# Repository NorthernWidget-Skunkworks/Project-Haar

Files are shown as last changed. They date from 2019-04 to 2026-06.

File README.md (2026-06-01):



# Project-Haar

***Mechanical, electrical, and firmware files for a rugged and submersible temperature, pressure, and relative-humidity sensor***

## Namesake and history

Haar in Ben Bhraggie Woods, Sutherland
***Haar in Ben Bhraggie Woods, Sutherland, Scotland.*** *Photo by Andrew Tryon.*

Project Haar takes its codename from the [North Sea fogs that roll across Britain](https://en.wikipedia.org/wiki/Haar_(fog)).
[Bobby Schulz](https://github.com/bschulz1701) designed it after the consistently-near-0C temperatures and 100% relative humidity of [Chimborazo Volcano](https://en.wikipedia.org/wiki/Chimborazo), Ecuador, claimed the lives of many brave but misguided [BME-280](https://www.adafruit.com/product/2652) units, who then catastrophically bricked their I2C buses and those of their associated data loggers, thus taking down a large fraction of our hydromet network.

Determined to avoid future issues with persistently condensing humidity, we worked to design a unit that would survive in this environment, and indeed, withstand full submersion.

## Technical specifications
<picture>
  <source media="(prefers-color-scheme: dark)" srcset="Documentation/images/Haar_v010_top_annotated_20200427_LIGHT.png">
  <!-- <source media="(prefers-color-scheme: light)" srcset="Documentation/images/Haar_v010_top_annotated_20200427.png"> -->
  Haar bare board
</picture>
<!-- ![Haar bare board](Documentation/images/Haar_v010_top_annotated_20200427.png) -->

### Electronic Hardware

* Microcontroller (computer) core
  * ATTiny1634
  * [Firmware](Firmware/) written in Arduino-compatible C++
  * Firmware upload via a [0.05" (1.27 mm) pitch 2x3 ICSP header](https://www.digikey.com/product-detail/en/samtec-inc/FTS-103-01-L-D/SAM1156-03-ND/1109979)
* Sensors
  * Relative humidity and temperature sensor: [SHT35-DIS-F2.5KS](https://www.digikey.com/product-detail/en/sensirion-ag/SHT35-DIS-F2.5KS/1649-1067-1-ND/6212138) with [PTFE membrane](https://www.sensirion.com/fileadmin/user_upload/customers/sensirion/Dokumente/2_Humidity_Sensors/Datasheets/Sensirion_Humidity_Sensors_SHT3x_Datasheet_Filter_Membran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) for water and dust protection
    * Humidity
      * Range: 0--100%
      * Accuracy: ±1.5%
      * Resolution: 0.01%
      * Long-term drift: <0.25%/yr
    * Temperature
      * Range: -40--125 °C
      * Accuracy: ±0.2 °C
      * Resolution: 0.01 °C
      * Long-term drift: <0.01 °C/yr
  * Atmospheric pressure and temperature sensor: [LPS35HW](https://www.st.com/en/mems-and-sensors/lps35hw.html)
    * Pressure
      * Range: 260 to 1260 mbar
      * Accuracy, calibrated: ±1 mbar
      * Accuracy, uncalibrated: ±4 mbar
      * Resolution: 1/4096 mbar (approx. 0.00024 mbar)
    * Temperature
      * Range, full accuracy: 0 to 60 °C
      * Accuracy: ±1.5 °C
      * Resolution: 0.01 °C
* Connections and communications protocols
  * [4-pin "HardMount" plug](https://www.digikey.com/product-detail/en/te-connectivity-amp-connectors/1838893-2/A97650-ND/1764165) ([3D drawing](http://www.te.com/commerce/DocumentDelivery/DDEController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))
  * I2C
* Power
  * Voltage limits: 3.3V ~ 5.5V
  * Power consumption: 
    * Peak = 5.21mA @ 3.3V
    * Sleep = 0.524 mA @ 3.3V
    * Mean (5 Hz sample rate) = 0.583 mA @ 3.3V
    * Mean (1 Hz sample rate) = 0.780 mA @ 3.3V
* Submersible with its Gore-Tex sealed housing
* Entirely IP67 or greater rated components
* Response Time
  * Temperature: &tau; = 377s
  * Humidity: &tau; = 505s
  * Pressure: &tau; &lt;1s

### Electronic Software and Firmware

* Programmable using the Arduino IDE https://www.arduino.cc/en/main/software
* [Firmware](Firmware/) available in this repository. [`Haar_Firmware.ino`](Firmware/Haar_Firmware/Haar_Firmware.ino) is the standard firmware to be used. 
* [Software](https://github.com/NorthernWidget-Skunkworks/Haar_Library) to use this sensor with Arduino-compatible devices
* Open-source licensing via GNU GPL 3.0

### Weatherproofing and enclosure
* Low-VOC conformal coating as recommended on Page 3 of the [humidity and temperature sensor data sheet](https://www.sensirion.com/fileadmin/user_upload/customers/sensirion/Dokumente/2_Humidity_Sensors/Application_Note/Sensirion_Humidity_Sensors_Handling_Instructions.pd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). We used [Dow Corning 1-2577 Low VOC Conformal Coating](https://www.digikey.com/product-detail/en/1-2577+CONFORMAL+CTG+453G/2275-1-2577CONFORMALCTG453G-ND/11494980/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).
* Fully sealed housing with removable [breathable-membrane (IP68) vent](https://www.digikey.com/product-detail/en/amphenol-ltw/VENT-PS1NGY-O8002/1754-1221-ND/7898276)

> [!WARNING]
> If applying conformal coating, ensure none comes in contact with the sensor orifices themselves, see Senserion Handling Instructions [example](Documentation/images/ConformalApplication.png)

Haar: in housing

## Assembly

### Sensor circuit board

[Bill of Materials](Production/Haar_HardMount_BoM_0v1.csv)

[PCB Gerber Files](Production/Gerbers_2020-02-20.zip)

Assembling this sensor is possible by hand with sufficient skill and the following tools:
* Temperature-controlled soldering iron
* Hot-air rework station
* Equipment for stenciling with solder paste
* ESD-safe tweezers and workstation
* Solder wick

Many components on this board are fine pitch and/or have difficult to access pads. However, there are not very many components. We would suggest hand assembly using tweezers, stenciled solder paste, and a hot-air rework station. A soldering iron will be helpful -- if not outright essential -- for attaching the "Hard Mount" plug and (if desired) the 2x3 pin ICSP header to upload the firmware.
<!-- >> THOUGHT: I have basic instructions for assembly on the [Project Walrus](https://github.com/NorthernWidget-Skunkworks/Project-TPDH-Walrus) README; I will not reproduce these here just yet, as we might want to set up a separate assembly guide, mostly with good links to existing resources, since our writing something of this nature would be to reinvent the wheel. -->

After finishing the main board assembly, solder the HardMount plug onto the four SMD pads with the notch (for plug orientation) at the bottom side of the board.

### Housing and cabling

Haar: exploded view

Two different housings have been designed to be used in different situations depending on how much robustness is required by the sensor. 
**Closed:**
For maximal robustness a [sealed IP67 rated housing](Mechanical/ClosedBody/ClosedBody.stl) was designed. This housing can be constructed using FDM printing with ABS plastic and acetone smoothing - an [FDM optimized version](Mechanical/ClosedBody_FDM/ClosedBody_FDM.stl) of the design was made featuring an eyelet to hang the enclosure from during the smoothing process. However, results will be significantly better with PA12 SLS nylon - readily available from many print houses.

Render of Closed Enclosure

**Open:**
For maximal responsiveness an [open structure enclosure](Mechanical/OpenBody/OpenBody.stl) was designed to allow airflow while still protecting the sensor from mechanical damage. This enclosure has been tested with FDM and SLA printing, methods will depend on your desired material properties.

Render of Closed Enclosure

#### Parts required

* Sealing plug with cable such as this [-40 degree PVC-jacketed one](https://www.digikey.com/product-detail/en/alpha-wire/AR0400105-SL357/AR0400105SL357-ND/6555497) or [this set of Digi-Key search results for all those that are 3 meters or less in both -40 degree rated PVC and in ](https://www.digikey.com/products/en/cable-assemblies/circular-cable-assemblies/448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); these come in [a variety of lengths from 0.6 to 20 meters](http://www.alphawire.com/en/Products/Connectivity/AlphaConnect/Cordsets/AR0400105) ([Digi-Key search results](https://www.digikey.com/products/en/cable-assemblies/circular-cable-assemblies/448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)). You may also [attach a plug to your own cable](http://www.alphawire.com/en/Products/Connectivity/AlphaConnect/FieldAttachable/200ARS7). Note that I2C communications become iffy for any cable longer than 3 meters.
* [3D-printed housing barrel](Mechanical/ClosedBody_FDM), tapped (see below). We recommend light-colored plastic to reduce radiative heating.
* [4-pin HardMount plug](https://www.digikey.com/product-detail/en/te-connectivity-amp-connectors/1838893-2/A97650-ND/1764165)
* [Amphenol breathable vent](https://www.digikey.com/product-detail/en/amphenol-ltw/VENT-PS1NGY-O8002/1754-1221-ND/7898276)

#### Soldering the HardMount attachment to your board

If it is not already attached, you will need to solder the [4-pin HardMount plug](https://www.digikey.com/product-detail/en/te-connectivity-amp-connectors/1838893-2/A97650-ND/1764165) onto the four SMD pads at the end of the board far from the isolated humidity sensor. You should do so with the notch (for plug orientation) at the bottom side of the board.

Our recommendation for by-hand assembly:
* Add small pillows of solder to each of the four pads, enough to create contact with the HardMount solder cups but not so much that it is not possible to slide the HardMount plug over them.
* Slide the HardMount plug on; it will take a bit of finesse to keep it from being pushed off of the solder pillows.
* Using some Blu Tack (or equivalent), fix the board and HardMount plug in place
* Double-check that the notch in the HardMount plug is on the back side of the board
* Solder on the first connection
* Check whether the board is straight; reflow the solder as needed until the connection is secure
* Solder the second connection
* Flip the board, ensuring that it is straight (if not, make changes)
* Solder the other two solder-cup connections

> [!TIP]
> Sometimes the 3D printed threads are not sufficiently fine to work smoothly. In this case, you can 'repair' the threads using a metal tap. 
>
> The cable side thread is an [M16 x 1.5](https://www.mcmaster.com/26015A263/), and the vent side is a [M12 x 1.5](https://www.mcmaster.com/26015A613/) - More economical taps can be found, these placed here for referance.

#### Cable

Here we assume that you are using [standard Alpha Wire cables with waterproof attachments]([Alpha Wire 5004C](https://www.digikey.com/product-detail/en/alpha-wire/5004C-SL001/5004CSL001-ND/484976). Because of the wire insulation colors available for these cables and the locations of their attachment points to the [4-pin "HardMount" plug](https://www.digikey.com/product-detail/en/te-connectivity-amp-connectors/1838893-2/A97650-ND/1764165) ([3D drawing](http://www.te.com/commerce/DocumentDelivery/DDEController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)), **our HardMount devices do NOT match standard wire-color definitions (or any kind of standard)**. Wire-color definitions are:

<picture>
  <source media="(prefers-color-scheme: dark)" srcset="Documentation/images/Pinout_LIGHT.png">
  Haar Connector Pinout
</picture>

| **Color** | **Connection** |
|---|---|
| Brown | V+ (3.3-5.5 V) |
| White | GND |
| Black | SDA |
| Blue | SCL |

For reference, these are the definitions of the four pads to which the [HardMount connector](https://www.digikey.com/product-detail/en/te-connectivity-amp-connectors/1838893-2/A97650-ND/1764165) attaches:
* Top left: SDA
* Top right: SCL
* Bottom left: VCC (3.3V to 5.5V)
* Bottom right: GND

## Firmware

### Downloading and installing the Arduino IDE

Go to https://www.arduino.cc/en/main/software. Choose the proper IDE version for your computer. For Windows, we suggest the non-app version to have more control over Arduino; this might change in the future. You will have to add custom libraries, so the web version will not work (at least, as of the time of writing). Download and install the Arduino IDE. Open it to begin the next steps.

### AVR ISP

To install firmware on the Haar board, you use the [2x3-pin 6-pin ICSP (also called ISP) header](https://www.digikey.com/product-detail/en/samtec-inc/FTS-103-01-L-D/SAM1156-03-ND/1109979) with a special device called an "in-circuit system programmer" (or just "in-system programmer; yup, that's what the acronym stands for).

Many devices exist to upload firmware, including:
* The official [AVR ISP mkII](http://ww1.microchip.com/downloads/en/DeviceDoc/Atmel-42093-AVR-ISP-mkII_UserGuide.pdf) (no longer produced but available used)
* Using an [Arduino as an ISP](https://www.arduino.cc/en/tutorial/arduinoISP)
* The versatile [Olimex AVR-ISP-MK2](https://www.olimex.com/Products/AVR/Programmers/AVR-ISP-MK2/open-source-hardware) (recommended)
* The [Adafruit USBtinyISP](https://www.adafruit.com/product/46)

> [!IMPORTANT] 
> The Haar has a [half-sized (0.05" pitch) ICSP header](https://www.digikey.com/product-detail/en/samtec-inc/FTS-103-01-L-D/SAM1156-03-ND/1109979). Therefore, you will need to have the appropriate 2x3-pin header to form a connection - see detailed [assmbly instructions](Hardware/ISP_Cable_Assembly.md).

<!-- ***Note: Be sure to download and/or update drivers for your ISP.*** -->

> [!NOTE]
> Frequently on Windows machines the driver configuration of the ISP programmer can become problematic. See discussion of how to get drivers and the use of Zadig to configure them in this [Sparkfun Guide](https://learn.sparkfun.com/tutorials/pocket-avr-programmer-hookup-guide/installing-drivers)

### Uploading the firmware

Using this ISP, upload (as of the time of writing): [the Arduino sketch in this folder](Firmware/Haar_Firmware/). To do so, follow these steps:

1. Open the Arduino IDE.
2. Follow [these instructions](https://github.com/SpenceKonde/ATTinyCore/blob/master/Installation.md) to install the [ATTinyCore board definitions](https://github.com/SpenceKonde/ATTinyCore)
3. Select [ATTiny1634](https://github.com/SpenceKonde/ATTinyCore/blob/master/avr/extras/ATtiny_1634.md) **(No bootloader)**

> [!CAUTION]
> Check your ISP target voltage before you connect! Make sure the target voltage is set to 3.3v, 5v can damage the sensor irreparably 

4. Plug your ISP of choice into your computer (via a USB cable) and onto the 6-pin header. There are two ways to place it on; the header is aligned such that the ribbon cable should be facing away from the board while programming. If this fails without being able to upload, try flipping the header around. This should both power the board and provide communications.
5. Go to Tools --> Programmer and select the appropriate programmer based on what you are using.
6. Go to Tools --> Burn Bootloader. Yes, we know that you just selected "ATTiny1634 (No bootloader)", but this step sets the fuses, which configure their internal oscillator and brown-out detection.
7. Go to Sketch --> Upload Using Programmer. After several seconds, you learn whether you succeeded or failed. Hopefully it worked!

Upload using programmer

***Uploading using the in-system programmer.***

> [!NOTE] 
> **Linux Users:** You must supply permissions to the Arduino IDE for it to be able to use the ICSP, or you will have to run it using `sudo`. The former option is better; the latter is easier in the moment.

## Register map and firmware internals

The Haar firmware runs on an ATTiny1634 and exposes an I2C register map to the host logger. The default I2C address is `0x42`.

The device exposes a flat, byte-addressable virtual address space. The master writes a 1-byte starting address, then reads up to 32 bytes in one transaction. Pages are 32-byte aligned.

Two layouts exist: the **current firmware** (deployed) and the **proposed** layout under [NW-Device-Specification](https://github.com/NorthernWidget/NW-Device-Specification) Schema 1, which the firmware will be updated to implement.

### Current register map (deployed firmware)

10-byte array, no schema byte, no device name. The library reads one register at a time (no bulk page read). The master triggers a conversion by writing `0x01` to address `0x00`; the firmware clears bit 0 when the measurement is complete.

```
0x00        Config       bit 0 = sample trigger (master writes 1; cleared when done)
0x01        —            unused
0x02–0x03   Temp LPS35HW int16, raw (library: val/100.0 → °C)
0x04–0x05   Temp SHT31   uint16, raw SHT31 counts (library: -45 + 175×val/65535 → °C)
0x06–0x08   Pressure     24-bit, raw LPS35HW counts (library: val/4096.0 → hPa)
0x09–0x0A   Humidity     uint16, raw SHT31 counts (library: 100×val/65535 → % RH)
             ⚠ 0x0A is out of bounds — Reg[10] ends at 0x09
```

### Proposed register map (NW-Device-Specification Schema 1)

Two 32-byte pages. Identity is EEPROM-backed; sensor data is SRAM-backed. No calibration page (both sensors are factory-calibrated with no user calibration step).

**Page 0 (0x00–0x1F) — Identity (EEPROM)**

```
Block 0 (0x00–0x07)   Core identity
  0x00        0x01              Schema (NW-Device-Specification v1)
  0x01–0x04   'H','a','a','r'   Device name (ASCII)
  0x05–0x07   0x00,0x00,0x00    Null padding

Block 1 (0x08–0x0F)   Version
  0x08        HW major
  0x09        HW minor
  0x0A        FW patch          (NW combined-repo convention)
  0x0B–0x0D   0x00,0x00,0x00    Unused (combined repo)
  0x0E–0x0F   0x00,0x00         Reserved

Block 2 (0x10–0x17)   Serial number
  0x10–0x11   0x48,0x01         Board type ('H' = 0x48, revision index 1)
  0x12–0x13   [manufacture]     Group ID
  0x14–0x15   [manufacture]     Unique ID
  0x16–0x17   0x00,0x00         FirmwareID (legacy, reserved)

Block 3 (0x18–0x1F)   Integrity + administration
  0x18–0x1C   0x00 ×5           Reserved
  0x1D        0x00              Magic byte (reserved; purpose TBD)
  0x1E        [computed]        CRC-8 of bytes 0x00–0x1D
  0x1F        0x42              I2C address (writable; 0xFF = use default)
```

**Page 1 (0x20–0x3F) — Sensor data (SRAM)**

```
Block 0 (0x20–0x27)   SHT31 — temperature + humidity
  0x20        Status       bit 0=ready, bit 1=SHT31 fault, bit 2=LPS35HW fault,
                           bit 7=pan-fault
  0x21        Extended faults (reserved, 0x00)
  0x22–0x23   Temp SHT31   int16, 0.01 °C, little-endian
  0x24–0x25   Humidity     uint16, 0.01 % RH, little-endian
  0x26–0x27   Reserved

Block 1 (0x28–0x2F)   LPS35HW — pressure + temperature
  0x28–0x2B   Pressure     uint32, 0.01 hPa, little-endian
  0x2C–0x2D   Temp LPS35HW int16, 0.01 °C, little-endian
  0x2E–0x2F   Reserved

Block 2–3 (0x30–0x3F)   Reserved
```

Check bit 0 of 0x20 before using any measurement. If clear, all other Page 1 bytes are stale.

---

## Writing a program to connect to the Haar sensor

Once the  is bootloaded and connected with a LiDAR Lite sensor, you should be able to use any standard Arduino device to connect to it and read its data.

### Very simple Arduino code

This code is intended for any generic Arduino system.

```c++
// Include the Haar library
#include "Haar.h"

// Declare variables -- just as strings
String header;
String data;

// Instantiate class
Haar myTPRH;

void setup(){
    // Begin Serial connection to computer at 38400 baud
    Serial.begin(38400);
    // Obtain the header just once
    header = myTPRH.getHeader();
    // Print the header to the serial monitor
    Serial.println(header);
}

void loop(){
    // Take one reading every (10 + time to take reading) seconds
    // and print it to the screen
    myTPRH.updateMeasurements();
    data = myTPRH.getString();
    Serial.println(data);
    delay(10000); // Wait 10 seconds before the next reading, inefficiently
}
```

### Northern Widget Margay code

The [Margay data logger](github.com/NorthernWidget-Skunkworks/Project-Margay) is the lightweight and low-power open-source data-logging option from Northern Widget. It saves data to a local SD card and includes on-board status measurements and a low-drift real-time clock. We have written [a library to interface with the Margay](github.com/NorthernWidget-Skunkworks/Margay_Library), which can in turn be used to link the Margay with sensors.

```c++
// Include the libraries
#include "Margay.h"
#include "Haar.h"

// Declare variables -- just as strings
String header;
String data;

// Instantiate classes
Haar myTPRH;
Margay Logger; // Margay v2.2; UPDATE CODE TO INDICATE THIS

// Empty header to start; will include sensor labels and information
String Header = "";

// I2CVals for Haar
uint8_t I2CVals[] = {0x42}; // DEFAULT

//Number of seconds between readings
uint32_t updateRate = 60;

void setup(){
    Header = Header + myTPRH.getHeader();
    Logger.begin(I2CVals, sizeof(I2CVals), Header);
    initialize();
}

void loop(){
    initialize();
    Logger.run(update, updateRate);
}

String update() {
    initialize();
    return myTPRH.getString();
}

void initialize(){
    myTPRH.begin();
}
```

### Northern Widget Okapi code

>> Currently nearly identical to Margay code, by design. Add telemetry with Particle Boron.

```c++
// Include the libraries
#include "Okapi.h"
#include "Haar.h"

// Declare variables -- just as strings
String header;
String data;

// Instantiate classes
Haar myTPRH;
Okapi Logger;

// Empty header to start; will include sensor labels and information
String Header = "";

// I2CVals for Haar
uint8_t I2CVals[] = {0x42}; // DEFAULT

//Number of seconds between readings
uint32_t updateRate = 60;

void setup(){
    Header = Header + myTPRH.getHeader();
    Logger.begin(I2CVals, sizeof(I2CVals), Header);
    initialize();
}

void loop(){
    initialize();
    Logger.run(update, updateRate);
}

String update() {
    initialize();
    return myTPRH.getString();
}

void initialize(){
    myTPRH.begin();
}
```

## Characterization

### Response time

<!-- ![Lab fridge test](Documentation/images/Haar_T9602_vent_test_lab_fridge.png)

***Response-time testing.*** *Our initial tests demonstrate that, with the vent detached, the Haar exhibits sensitivity and response time similar to the [T9602 temperature and relative humidity sensor](https://www.amphenol-sensors.com/images/stories/moisture-humidity/main-T9602-Mod-4.png). With the vent cap on, this response is dampened significantly.* -->
This sensor was tested for using an impulse for each variable (temperature, pressure, humidity) and for each housing type (closed, open). The details of each of these evaluations can be found in the testing documentation: [Temperature](Testing/Temperature/README.md), [Pressure](Testing/Pressure/README.md), [Humidity](Testing/Humidity/README.md). A summary of these results, along with visuals of the step response, is presented here.

Approximate time to equilibrium for each variable and sensor type
| **Sensor** | Temperature | Pressure | Humidity | 
|---:|:---:|:---:|:---:|
| Control | 105s | &lt;1s | 18 min |
| Haar, Closed | 75s | &lt;1s | 31.75 min |
| Haar, Open | 12.5 min | &lt;1s | 10.25 min |

Temperature Step Response Graph

Humidity Step Response Graph

This response time information should serve as a guide to the choice of housing. In situations where very fast response time is required *and* the sensor will not be subjected to environmental extremes (e.g. in a radiation shield on a meteorological station) an open housing can be used. However, in cases where the hazards of the environment are a priority (e.g. a sensor in the flood plane of a river to calibrate a depth sensor) a closed housing should be used.

<!-- >> @bschulz1701: Application note about when to use the cap? Notes about the IP ratings of the devices and practical ratings as well? And I've been looking for a M12 vent without any membrane so it can still physically protect the sensor (or act as a roof for rain) but have not yet found one. Thoughts on this?
>> @awickert: The cap would desire to be used when there is the potential for the device to become fully submerged and slow response time is not a problem (for getting system averages instead of response time or quick variance). All elements of the device (uncapped) are rated to >IP67, however, the conformal coating of the board is not specifically rated for any pressure. It would likely survive breif immersion but not for extended periods of time. As for the a cap with no membrane: since be 3D print the body, we would just design a body with a "roof" instead of a thread at the top, and holes or slots in the side, whichever we desire. Then instead of replacing the end cap, you just replace the entire body (which just screws on to the bottom). This would actually make it a bit easier to make, since it would be one less thread that would need to be made by hand. -->

## NW-Device-Specification — Schema 1, Page 0

Implements [NW-Device-Specification](https://github.com/NorthernWidget/NW-Device-Specification) Schema 1. The 32-byte identity block (Page 0) is stored at the top of EEPROM:

```
Block 0:  Schema=0x01, Name='H','a','a','r',0x00,0x00,0x00
Block 1:  HW major=[mfr], HW minor=[mfr], FW patch=[mfr], 0x00,0x00,0x00, Reserved
Block 2:  Board type=0x4801 ('H'=0x48, rev 1), Group ID=[mfr], Unique ID=[mfr], FirmwareID=0x0000
Block 3:  Reserved, Magic=0x00, CRC=[computed], I2C address=0x48
```

Legacy deployed units use I²C address `0x42` (pre-Schema-1).

## Acknowledgments

Support for this project provided by:

UMN ESCI
<br/>
<br/>
NSF

WMO

<br/>
<br/>
<br />This work is licensed under a <a rel="license" href="http://creativecommons.org/licenses/by-sa/4.0/">Creative Commons Attribution-ShareAlike 4.0 International License</a>.

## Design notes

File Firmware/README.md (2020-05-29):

`"Haar_Firmware.ino`: current most final firmware: still needs a bit of cleanup, but has full functionality.

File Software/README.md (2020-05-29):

`Haar_InterfaceDev.ino` is a development script used for testing the functionality of the Haar firmware be reading from the device (this code is meant to be run on the logger side for testing and development only)

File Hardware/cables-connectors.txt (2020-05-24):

"HardMount" plug: TE Connectivity 1838893-2: https://www.digikey.com/product-detail/en/te-connectivity-amp-connectors/1838893-2/A97650-ND/1764165
"HardMount cable: Alpha Wire AR0400105 SL357: https://www.digikey.com/product-detail/en/alpha-wire/AR0400105-SL357/AR0400105SL357-ND/6555497
Cable for non-HardMount version: Alpha Wire 5004C: https://www.digikey.com/product-detail/en/alpha-wire/5004C-SL001/5004CSL001-ND/484976
0.05" pitch 2x3 ICSP header (optional; can hold in place as well): Samtec FTS-103-01-L-D: https://www.digikey.com/product-detail/en/samtec-inc/FTS-103-01-L-D/SAM1156-03-ND/1109979

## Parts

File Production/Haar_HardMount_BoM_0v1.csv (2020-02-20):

Qty | Value | Device | Package | Parts | Description | DIGIKEY | DISP | MF | MPN | PROD_ID | VALUE | VALUE_PART
1 |  | ATTINY1634QFN | QFN20 | U3 | ATtiny1634 8 bit AVR Microcontroller | ATTINY1634-MURCT-ND |  | Atmel | ATTINY1634-MUR
3 | 0.1uF | C-EU0.1UFC0402 | C0402 | C3, C4, C5 | CAPACITOR, European symbol | 490-4759-1-ND |  | Murata | GCM155R71C104KA55D
3 | 10k | R-EU_10KR0402 | R0402 | R1, R2, R3 | RESISTOR, European symbol | 311-10.0KHRCT-ND |  | Yageo | RC0603FR-0710KL |  |  | 10k
1 | 2.2uH | INDUCTOR0805 | 0805 | L1 | Genaric inductor | 732-2953-1-ND |  | Wurth | 74479775222
1 | 2N7002 | MOSFET-NCH-2N7002PW | SOT323 | Q1 | N-channel MOSFETs | 2N7002W-FDICT-ND |  | Diodes Incorporated | 2N7002W-7-F | TRANS-11151 | 2N7002
2 | 4.7uF | C-EUC0402 | C0402 | C1, C2 | CAPACITOR, European symbol | 490-14306-1-ND |  | Murata | GRM155R61A475MEAAD
1 | AVRISP1.27MM | AVRISP1.27MM | 2X3_1.27 | ISP1 | AVR ISP HEADER
1 | LPS35HW | LPS35HW | CCLGA10L | U2 | LPS3xHW - Digital Water Resistant Pressure Sensor | 497-16706-1-ND | LPS35HW | ST | LPS35HWTR
1 | SHT35DFN | SHT35DFN | DFN_8_2.5X2.5 | U1 | SHT3x - Digital Humidity and Temperature Sensor | 1649-1067-1-ND | SHT35 | Sensirion | SHT35-DIS-F2.5KS
1 | SOLDERCUP_CONN_QUAD | SOLDERCUP_CONN_QUAD | SOLDERCUP_CONN_QUAD | J1
1 | TPS62237DRY | TPS62237DRY | DRY0006A | U4 | TPS6223xx - Ultra Small Step Down Converter (Buck) | 296-39454-1-ND | TPS62237 | TI | TPS62237DRYR
1 | TXS0102DQM | TXS0102DQM | DQM_R-PX2SON-N8 | U5 | TXS0102 - 2 Channel Bidirectional Voltage Level Translator | 296-28435-1-ND |  | TI | TXS0102DQMR

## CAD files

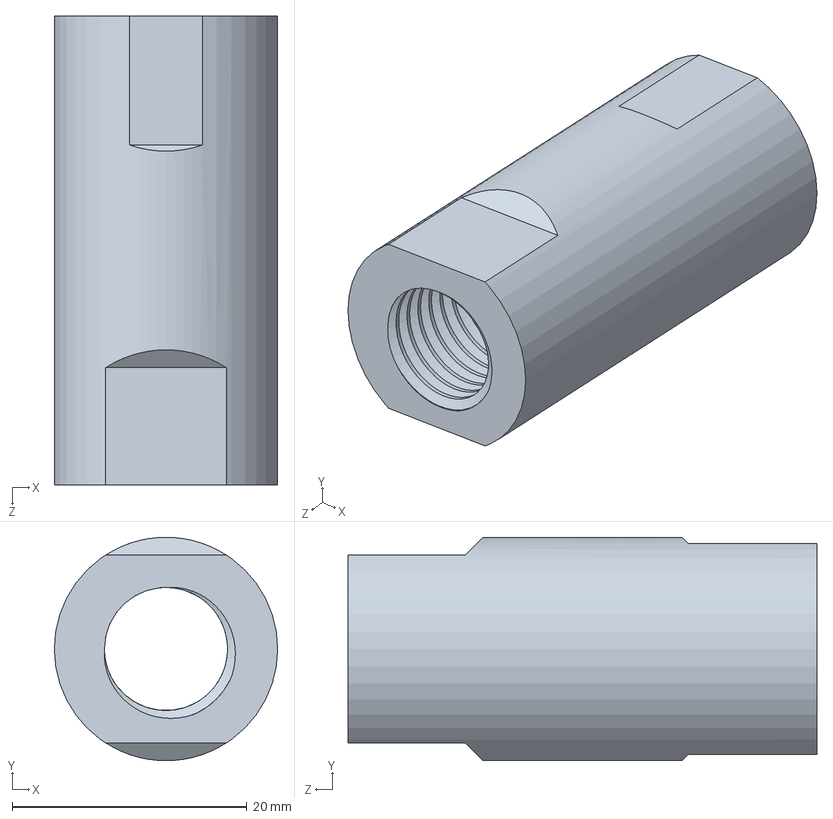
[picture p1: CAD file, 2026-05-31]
Mechanical/ClosedBody/ClosedBody.SLDPRT
19.1 x 19.1 x 40.0 mm

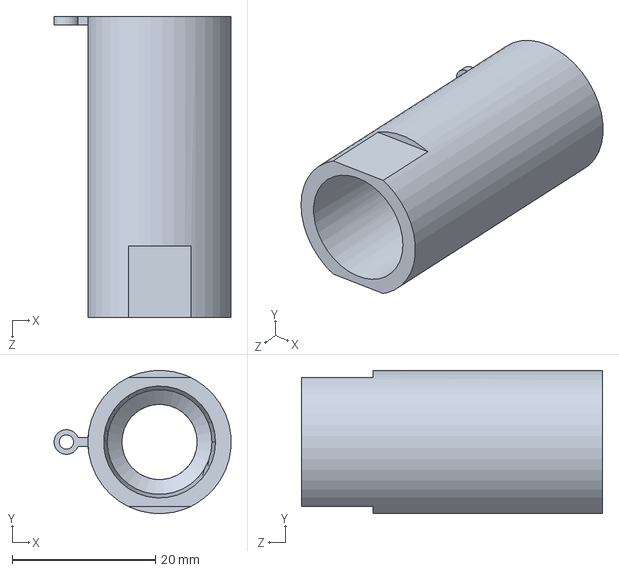
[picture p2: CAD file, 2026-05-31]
Mechanical/ClosedBody_FDM/ClosedBody_FDM.SLDPRT
24.7 x 20.0 x 42.0 mm

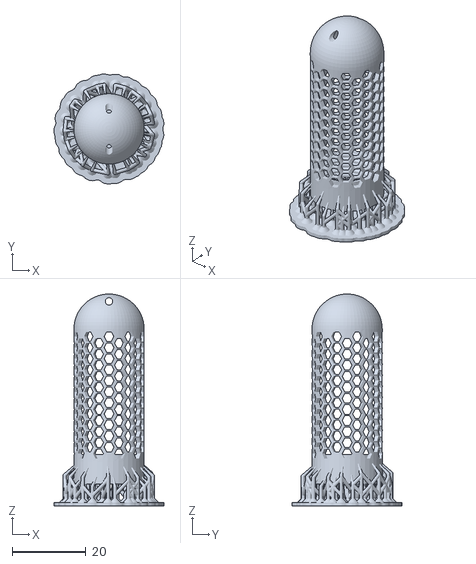
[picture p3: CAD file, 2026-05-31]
Mechanical/OpenBody/HAAR_001_-_OpenBody-v001_SUPPORTED.stl
29.8 x 29.9 x 57.5

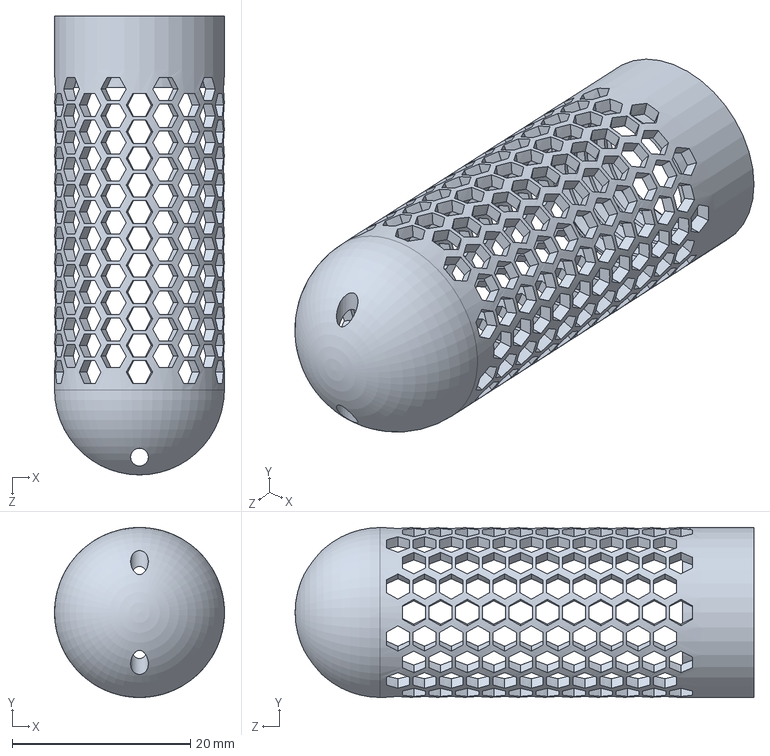
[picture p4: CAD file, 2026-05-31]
Mechanical/OpenBody/OpenBody.SLDPRT
19.1 x 19.1 x 51.5 mm

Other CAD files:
Mechanical/ClosedBody/ClosedBody.STL
Mechanical/ClosedBody_FDM/ClosedBody_FDM.STL
Mechanical/OpenBody/OpenBody.STL

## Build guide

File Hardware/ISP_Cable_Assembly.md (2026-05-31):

# ISP Cable Assembly Documentation 

### Components
* [10 Pos 0.1" Pitch Connector - 3M 89110-0101HA](https://www.digikey.com/en/products/detail/3m/89110-0101HA/1239030)
* [6 Pos 0.05" Pitch Connector - 3M 45106-000030](https://www.digikey.com/en/products/detail/3m/45106-000030/4475133)
* [Ribbon Cable, 30 AWG - Molex 1000570267](https://www.digikey.com/en/products/detail/molex/1000570267/6025715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)

### Assembly
* Install cable in 6 position connector using standard method
* Separate each wire in ribbon cable using x-acto knife and separate out several inches (about 2in/5cm)
* Insert each wire into the corresponding slot in the 10 position connector 
* Carefully clamp down the 10 position connector, being careful not to cross any of the wires

ICSP Pinout

#### Reference Material
[Olimex AVR ISP Mk2 Programming Interfaces](https://www.olimex.com/Products/AVR/Programmers/AVR-ISP-MK2/resources/isp-mk2-layout-connectors.png)

[6 Pos 0.05" Pitch Connector Datasheet](https://multimedia.3m.com/mws/media/905147O/3m-ribbon-cable-wiremount-socket-assembly-451-series-cd2436.pdf)

[10 Pos 0.1" Pitch Connector Datasheet](https://multimedia.3m.com/mws/media/22265O/3mtm-idc-ribbon-cable-socket-891-series-ts0449.pdf)

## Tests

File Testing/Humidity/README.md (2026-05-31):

# Testing - Humidity

A step response of humidity performance was evaluated with the use of a ultrasonic humidifier and a general purpose test chamber. 

### Procedure 
A pair of Haar sensors (`v0.1` hardware) were placed in a large (5 gallon) sealed chamber - see [Figure 1](images/Fig1.jpg). This chamber was left open and allowed to reach atmospheric equilibrium. Once the humidity was stabilized, an ultrasonic humidifier was used to inject a small amount of extremely humid air (>90%) into the test chamber, increasing the ambient humidity in the box by a small amount (<10%). Once this injection was completed, the inlet ports to the chamber were sealed - isolating the chamber. An ultrasonic humidifier was chosen as it can produce extremely humid air without appreciably affecting the temperature of the environment, which would add undesired variability to the test. This simulates an extreme example of a humidity due to a shift in weather system. Haar data was recorded until such time as both units had reached equilibrium.

Haar data was logged to a computer using the generic Haar [DataRecorder](../DataRecorder/DataRecorder.ino) script with `period` set to 1000ms. In addition, ground truth data was taken using a [HygroVue 10](https://www.campbellsci.com/hygrovue10) sensor. An [SDI-12 Symbiont](https://github.com/RTGS-Lab/Symbiont-SDI12) was used to interface the SDI-12 sensor with the microcontroller board. This data was captured using the [DataRecorder_HygroVue](../DataRecorder_HygroVue/DataRecorder_HygroVue.ino) script. These two captured sets of data were then merged into the single data file presented below.

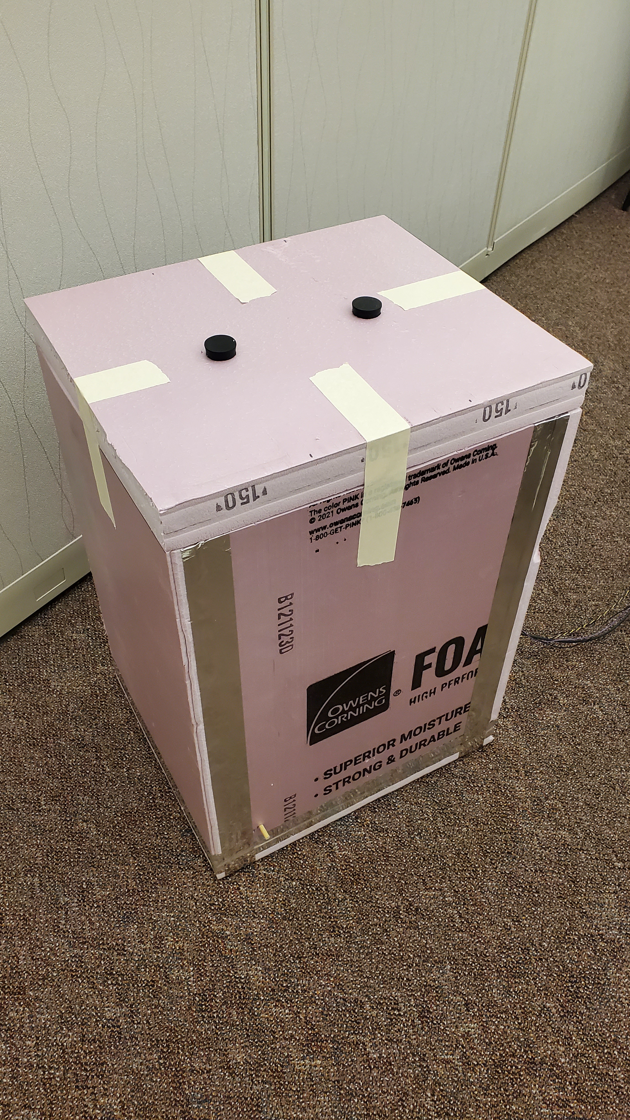
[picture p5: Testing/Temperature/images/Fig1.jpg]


### Analysis

The sensor with an open enclosure has an almost immediate response, as expected. This is used to establish a start time of the test. We then identify the equilibrium value (max value measured by the sensor in the vented enclosure). The time constant of the system (&tau;) is defined as the time in which is takes the system to reach FinalVal x (1 - 1/e) which is equal to 0.6321 x FinalVal. 

Response times are evaluated for all devices involved and compared in the table below

| **Sensor** | **Response Time (&tau;) [s]** | **Approx. Time to Equilibrium [s]** |
|---:|:---:|:---:|
| HygroVue 10 (Control) | 21 | 105 |
| Haar, Closed | 15 | 75 |
| Haar, Open | 150 | 750 |

The worst case response, as expected, is the closed Haar sensor. Despite this, we find a time to equilibrium of **just over 12 minutes**, which is perfectly reasonable in most situations. Additionally, the open Haar sensor out performs the control sensor. 

Step Response

[Python](HumidityAnalysis.py)

[Jupyter Notebook](HumidityAnalysis.ipynb)

### Data

[File](Data.csv)

Sensor A - Haar sensor with open 3D printed enclosure 

Sensor B - Haar sensor with solid 3D printed enclosure and Gore-Tex vent

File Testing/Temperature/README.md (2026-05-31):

# Testing - Temperature

A test was conducted using a custom built temperature controlled box in order to evaluate the variance in response with an open housing verses a housing with a GoreTex vent  

### Procedure 
A pair of Haar sensors (`v0.1` hardware) were placed in open air and allowed to fully acclimate to stable room temperature (minimum of 60 minutes at a temperature of approximately 16°C). Once this is completed, the sensors are placed into a thermal regulated box held (construction discussed [here](#thermal-regulated-box-construction)) at a temperature of 25°C by a heater and [PID controller](../BoxPID/BoxPID.ino). Data from the sensors is recorded until after equilibrium is achieved. This procedure subjects the sensors to step response in order to determine the thermal characteristics. 

Haar data was logged to a computer using the generic Haar [DataRecorder](../DataRecorder/DataRecorder.ino) script with `period` set to 1000ms. In addition, ground truth data was taken using a [HygroVue 10](https://www.campbellsci.com/hygrovue10) sensor. An [SDI-12 Symbiont](https://github.com/RTGS-Lab/Symbiont-SDI12) was used to interface the SDI-12 sensor with the microcontroller board. This data was captured using the [DataRecorder_HygroVue](../DataRecorder_HygroVue/DataRecorder_HygroVue.ino) script. These two captured sets of data were then merged into the single data file presented below.   

### Analysis

The sensor with an open enclosure has an almost immediate response, as expected. This is used to establish a start time of the test. We then identify the equilibrium value (max value measured by the sensor in the vented enclosure). The time constant of the system (&tau;) is defined as the time in which is takes the system to reach FinalVal x (1 - 1/e) which is equal to 0.6321 x FinalVal. 

Response times are evaluated for all devices involved and compared in the table below

| **Sensor** | **Response Time (&tau;) [s]** | **Approx. Time to Equilibrium [min]** |
|---:|:---:|:---:|
| HygroVue 10 (Control) | 217 | 18 |
| Haar, Closed | 381 | 31.75 |
| Haar, Open | 124 | 10.25 |

The worst case response, as expected, is the closed Haar sensor. Despite this, we find a time to equilibrium of **just over 30 minutes**, which is perfectly reasonable in many situations. Additonally, the open Haar sensor greatly out performs the control sensor. 

Step Response

[Python](TemperatureAnalysis.py)

[Jupyter Notebook](TemperatureAnalysis.ipynb)

### Data

[File](Data.csv)

Sensor A - Haar sensor with open 3D printed enclosure

Sensor B - Haar sensor with solid 3D printed enclosure and Gore-Tex vent

#### Thermal Regulated Box Construction
An insulated box was constructed from 1.5 inch (3.81cm) thick Extruded Poly Styrene (XPS) insulation foam which has an R value (BTU / hr x ft^2 x &deg;F) of 7.5, creating a highly insulated test chamber. Overview of this box is shown in [Figure 1](images/Fig1.jpg) and measurments are shown in [Box Schematic](images/TempBoxDimensions_GREY.png). A series of holes are placed in the top of the box to allow entry for cables for test devices - surrounded by rubber stoppers. All edges of the box are sercured and sealed with foil tape to prevent heat loss through gaps.
<picture>
  <source media="(prefers-color-scheme: dark)" srcset="images/TempBoxDimensions_LIGHT.png">
  <!-- <source media="(prefers-color-scheme: light)" srcset="images/TempBoxDimensions_DARK.png"> -->
  Thermal Box Dimensions
</picture>
<!-- ![Box Schematic](images/TempBoxDimensions.png) -->

| **Dimension** | **H** | **W** | **D** | **h'** | **w'** | **d'** |
|---:|:---:|:---:|:---:|:---:|:---:|:---:|
| English (inch) | 28 | 16 | 19 | 25 | 13 | 16 |
| Metric (cm) | 71 | 44 | 41 | 63 | 33 | 44 |

Inside the box a temperature sensor ([T9602](https://www.amphenol-sensors.com/en/telaire/humidity/527-humidity-sensors/3224-t9602)), a 12V DC computer fan, and a coil of NiChrome wire are placed - this will along with a micro-controller and power supply constitutes the temperature control system. This contents can be seen in [Figure 2](images/Fig2.jpg). The box is heated by supplying current to the NiChrome coil via a Pulse Width Modulation (PWM) controlled 12V line. The fan is left running at full speed constantly to provide circulation within the box and ensure accurate and consistent temperature measurement. Temperature is sensed using the T9602 sensor by the micro-controller, then the output to the NiChrome heater is varied based on a simple PID controller implemented on the micro-controller. Between the insulation and the active control system the box maintains an accurate and, most importantly, stable temperature.


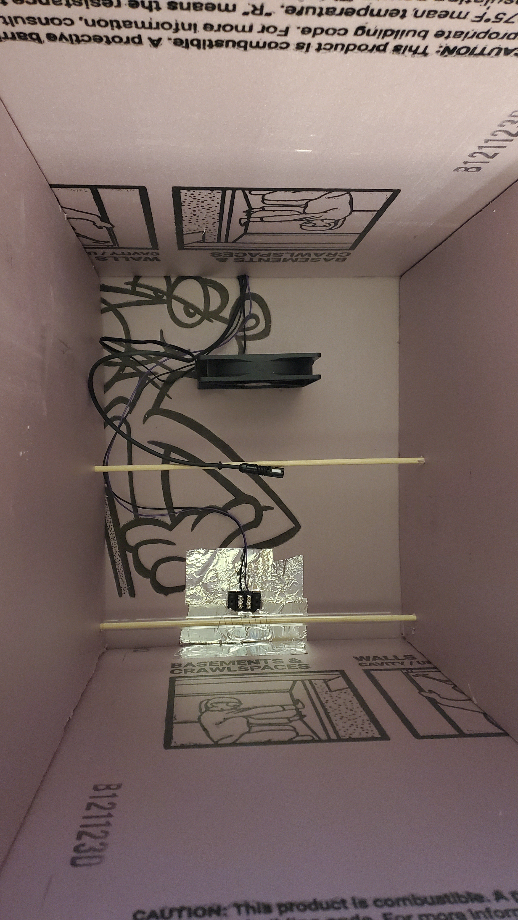
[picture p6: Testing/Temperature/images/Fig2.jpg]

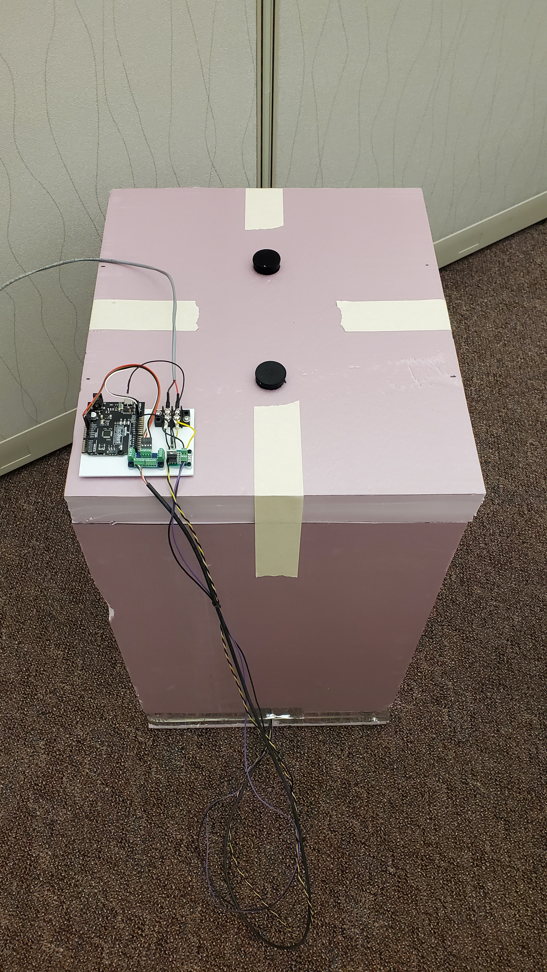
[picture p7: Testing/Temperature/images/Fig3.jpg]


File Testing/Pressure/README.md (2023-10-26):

# Testing - Pressure

Two different tests were performed to evaluate the system performance of Haar as a pressure sensor - a step change and a steady state response. In both tests, an ExTech SD700 was used as a standard of comparison. 

## Step Response

### Procedure 
A pair of Haar sensors (`v0.1` hardware) were placed in a large (5 gallon) sealed chamber - see [Figure 1](images/Fig1.jpg). This chamber was placed at a slight over-pressure (about 25 mBar) above atmospheric pressure. Once this pressure was stabilized, a ball valve was opened - rapidly returning the environment back to atmospheric pressure. This simulates the most extreme example of a pressure change one might see from a cold front, or other atmospheric phenomenon. Baseline pressure before and after the pressure change was recorded. 

Haar data was logged to a computer using the generic Haar [DataRecorder](../DataRecorder/DataRecorder.ino) script with `period` set to 100ms.



### Analysis

For both sensors the pressure before and after release is within sensor specs (4 mBar absolute error) and response time difference is insignificant between a Gore-Tex vent and an open housing. In both cases system fully responds well within 1 second

A basic plot of the response is created using [PressureAnalysis](PressureAnalysis.py) Python script - this script prints the resulting trimmed data and creates a simple plot

Step Response

[Python](PressureAnalysis.py)

[Jupyter Notebook](PressureAnalysis.ipynb)

### Data

[File](Data.csv)

Measured pressure before over pressure - 976.7 mBar

Measured pressure before release - 1003.2 mBar 

Measure pressure after release - 976.6 mBar

Sensor A - Haar sensor with solid 3D printed enclosure and Gore-Tex vent

Sensor B - Haar sensor with open 3D printed enclosure

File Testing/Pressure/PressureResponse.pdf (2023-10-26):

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

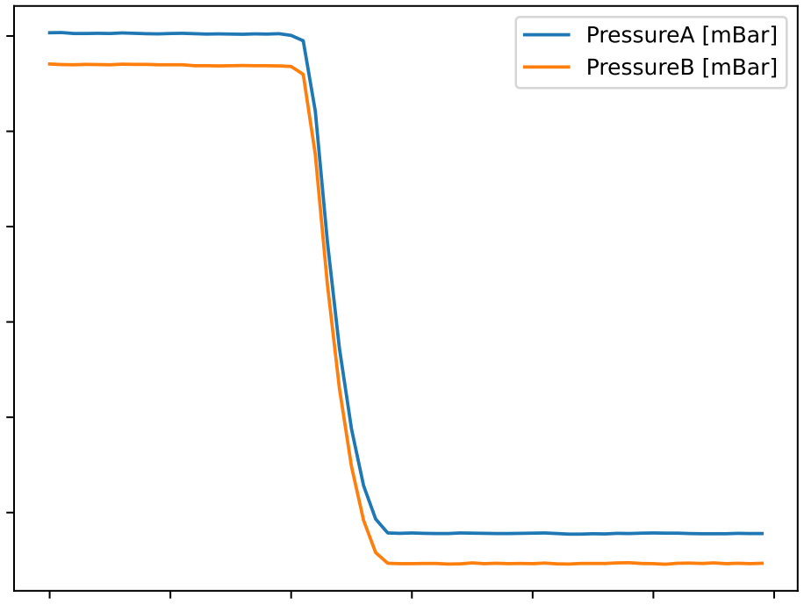
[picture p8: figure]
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

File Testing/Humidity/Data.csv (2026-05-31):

Time | TempCtrl | RHCtrl | PresA | TempA | RHA | PresB | TempB | RHB
8 | 22.05 | 45.09 | 969.5 | 22.15 | 48.12 | 970.95 | 22.18 | 50
11 | 22.05 | 45.11 | 969.47 | 22.19 | 48.02 | 970.94 | 22.18 | 50.05
14 | 22.07 | 45.1 | 969.48 | 22.09 | 48.11 | 970.92 | 22.18 | 50.05
17 | 22.05 | 45.1 | 969.5 | 22.2 | 48.18 | 970.92 | 22.2 | 50.02
20 | 22.04 | 45.16 | 969.53 | 22.23 | 48.19 | 970.97 | 22.2 | 50.02
23 | 22.05 | 45.15 | 969.5 | 22.16 | 48.13 | 970.91 | 22.17 | 50.01
26 | 22.04 | 45.11 | 969.52 | 22.13 | 48.07 | 970.95 | 22.2 | 50.04
29 | 22.05 | 45.11 | 969.51 | 22.24 | 48.06 | 970.95 | 22.2 | 50.05
32 | 22.04 | 45.11 | 969.52 | 22.13 | 48.12 | 970.97 | 22.18 | 50.02
35 | 22.05 | 45.13 | 969.54 | 22.26 | 48.16 | 970.94 | 22.21 | 50.01
38 | 22.05 | 45.13 | 969.49 | 22.15 | 48.11 | 970.96 | 22.2 | 50.04
41 | 22.05 | 45.08 | 969.5 | 22.12 | 48.09 | 970.93 | 22.18 | 50
44 | 22.04 | 45.16 | 969.5 | 22.12 | 48.18 | 970.95 | 22.18 | 50.01
47 | 22.07 | 45.11 | 969.55 | 22.15 | 48.22 | 970.95 | 22.2 | 50.01
50 | 22.05 | 45.1 | 969.51 | 22.16 | 48.06 | 970.94 | 22.18 | 50.06
53 | 22.05 | 45.14 | 969.54 | 22.22 | 48.15 | 970.95 | 22.2 | 50.04
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

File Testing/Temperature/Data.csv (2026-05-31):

Time | TempCtrl | RHCtrl | PresA | TempA | RHA | PresB | TempB | RHB
6.86 | 15.86 | 60.83 | 979 | 16.1 | 61.99 | 980.53 | 18.77 | 60.49
8 | 15.87 | 60.83 | 979 | 16.09 | 61.99 | 980.56 | 18.765 | 60.44
9 | 15.87 | 60.82 | 979 | 16.1 | 61.99 | 980.6 | 18.76 | 60.38
11 | 15.87 | 60.81 | 979 | 16.11 | 61.99 | 980.59 | 18.765 | 60.36
13 | 15.875 | 60.82 | 979 | 16.11 | 62 | 980.58 | 18.77 | 60.35
14 | 15.88 | 60.82 | 979 | 16.11 | 62.01 | 980.59 | 18.755 | 60.28
17 | 15.87 | 60.83 | 979.01 | 16.11 | 61.99 | 980.6 | 18.74 | 60.2
20 | 15.88 | 60.8 | 979 | 16.09 | 61.99 | 980.58 | 18.73 | 60.14
23 | 15.88 | 60.82 | 979.03 | 16.11 | 61.98 | 980.58 | 18.72 | 60.1
24 | 15.875 | 60.81 | 979.02 | 16.115 | 61.97 | 980.58 | 18.71 | 60.06
26 | 15.87 | 60.8 | 979 | 16.12 | 61.97 | 980.59 | 18.71 | 60
27 | 15.875 | 60.8 | 979.01 | 16.105 | 61.97 | 980.6 | 18.71 | 59.94
29 | 15.88 | 60.81 | 979.02 | 16.09 | 61.98 | 980.6 | 18.705 | 59.92
31 | 15.875 | 60.79 | 979.02 | 16.09 | 61.98 | 980.59 | 18.7 | 59.91
32 | 15.87 | 60.77 | 979.03 | 16.09 | 61.99 | 980.58 | 18.685 | 59.88
34 | 15.86 | 60.76 | 979.03 | 16.09 | 61.98 | 980.56 | 18.67 | 59.85
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

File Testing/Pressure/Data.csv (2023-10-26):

Time [ms] | TemperatureA [°C] | PressureA [mBar] | HumidityA [%] | TemperatureB [°C] | PressureB [mBar] | HumidityA [%]
16274 | 19.9023 | 1006.46 | 47.55 | 20.0679 | 1004.88 | 46.68
16374 | 19.8623 | 1005.28 | 47.68 | 20.0385 | 1003.63 | 46.73
16474 | 19.8890 | 1005.28 | 47.69 | 20.0385 | 1003.62 | 46.75
16574 | 19.8890 | 1005.26 | 47.68 | 20.0546 | 1003.58 | 46.75
16674 | 19.8756 | 1005.25 | 47.68 | 20.0546 | 1003.57 | 46.76
16774 | 19.9023 | 1005.26 | 47.72 | 20.0546 | 1003.58 | 46.70
16874 | 19.8890 | 1005.22 | 47.68 | 20.0252 | 1003.57 | 46.70
16974 | 19.8890 | 1005.23 | 47.67 | 20.0679 | 1003.59 | 46.76
17074 | 19.8890 | 1005.24 | 47.69 | 20.0546 | 1003.58 | 46.72
17174 | 19.9023 | 1005.24 | 47.71 | 20.0385 | 1003.58 | 46.71
17274 | 19.8756 | 1005.23 | 47.66 | 20.0546 | 1003.57 | 46.71
17374 | 19.9023 | 1005.19 | 47.67 | 20.0546 | 1003.58 | 46.70
17474 | 19.9184 | 1005.19 | 47.71 | 20.0813 | 1003.55 | 46.74
17574 | 19.9023 | 1005.18 | 47.68 | 20.0385 | 1003.56 | 46.68
17674 | 19.8890 | 1005.21 | 47.68 | 20.0546 | 1003.54 | 46.75
17774 | 19.8890 | 1005.19 | 47.67 | 20.0546 | 1003.52 | 46.77
17874 | 19.9023 | 1005.20 | 47.65 | 20.0385 | 1003.56 | 46.76
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

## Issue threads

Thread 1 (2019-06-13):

Add pullup resistors

bschulz1701, 2019-06-13:
### Issue:
For stability/reliability should add pullup resistors on `SDA` and `SCL` lines in hardware

Closed 2019-07-02.

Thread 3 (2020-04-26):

Housing parts

awickert, 2020-04-26:
Either in this repo or another, could we upload the parts list required to build the Haar housing and any STL files, etc.?

awickert, 2020-05-25:
Done.

Closed 2020-05-25.

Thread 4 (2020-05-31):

3D print non-PTFE vented housing

awickert, 2020-05-31:
The PTFE-vented housing increases the sensor response time and will, in many situations, be unnecessary. Let's design a new housing that terminates in a vented cap (a "roof"), with vents allowing appropriate drainage in case of water ingress. These designs can be modified from the cylinder in https://github.com/NorthernWidget-Skunkworks/Project-Haar/tree/master/3Dprint, replacing the narrow tappable portion for the PTFE vent with this "roof", and adding vents.

@superchap123 and @bschulz1701 and I have talked about this.

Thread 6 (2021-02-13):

Pinout for AlphaWire: switch to be more intuitive?

awickert, 2021-02-13:
**Current pinout:**
| **Color** | **Connection** |
|-----------|----------------|
| Brown     | V+ (3.3-5.5 V) |
| White     | GND            |
| Black     | SDA            |
| Blue      | SCL            |

**Proposed pinout:**
| **Color** | **Connection** |
|-----------|----------------|
| White     | V+ (3.3-5.5 V) |
| Black     | GND            |
| Brown     | SDA            |
| Blue      | SCL            |

See notes here about the switch:
https://github.com/NorthernWidget-Skunkworks/Project-Walrus/issues/3

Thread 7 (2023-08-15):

Documentation Fixes/To Do

bschulz1701, 2023-08-15:
## Issues

- [ ] Add manufacturing info for housing
- [ ] Confirm if housing 3D model is threaded or not?
- [ ] Transparent background on board image?
- [ ] Add hard mount pinout
- [ ] Add voltage limits for input power (in both limits section and pinout section)
- [ ] **Add power consumption figures**
- [ ] Fix 'indefinitely submersible' statement!
- [ ] **Measure response time**
- [ ] Add notes on where/how to apply conformal coating
- [ ] Confirm pinout with GEMS version
- [ ] Fix dead ESCI link
- [ ] Note on when to use/not use membrane
- [ ] **Add design for open cell housing**

### Response Time
- [ ] Temp - Room with space heater (vs T9602)
- [ ] Humidity - Room with humidifier (vs T9602)
- [ ] Pressure - Pull minor vacuum on carboy (vs uncovered Haar)
Repeat temp and humidity with normal cover and modified (open) cover

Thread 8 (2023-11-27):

Humidity Test

runck014, 2023-11-27:
The procedure doesn't specify the temperature the tests were performed at. At a minimum this should be recorded. Multiple temperature treatments would increase confidence in the enclosure and membrane.

runck014, 2023-11-27:
This would apply to the pressure test as well

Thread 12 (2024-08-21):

Include link to general assembly documentation?

bschulz1701, 2024-08-21:
Should we include a link to a generalized set of assembly documents, like those build around the Walrus board?

https://github.com/NorthernWidget-Skunkworks/Project-Walrus

"THOUGHT: I have basic instructions for assembly on the [Project Walrus](https://github.com/NorthernWidget-Skunkworks/Project-TPDH-Walrus) README; I will not reproduce these here just yet, as we might want to set up a separate assembly guide, mostly with good links to existing resources, since our writing something of this nature would be to reinvent the wheel."

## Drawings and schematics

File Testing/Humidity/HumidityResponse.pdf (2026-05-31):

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

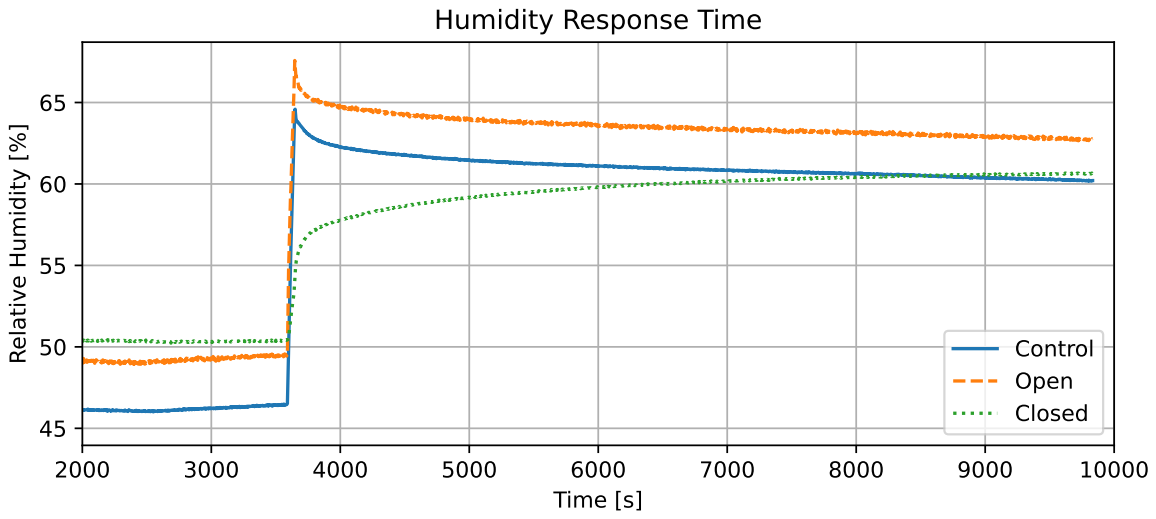
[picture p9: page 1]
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

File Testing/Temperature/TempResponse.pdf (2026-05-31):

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

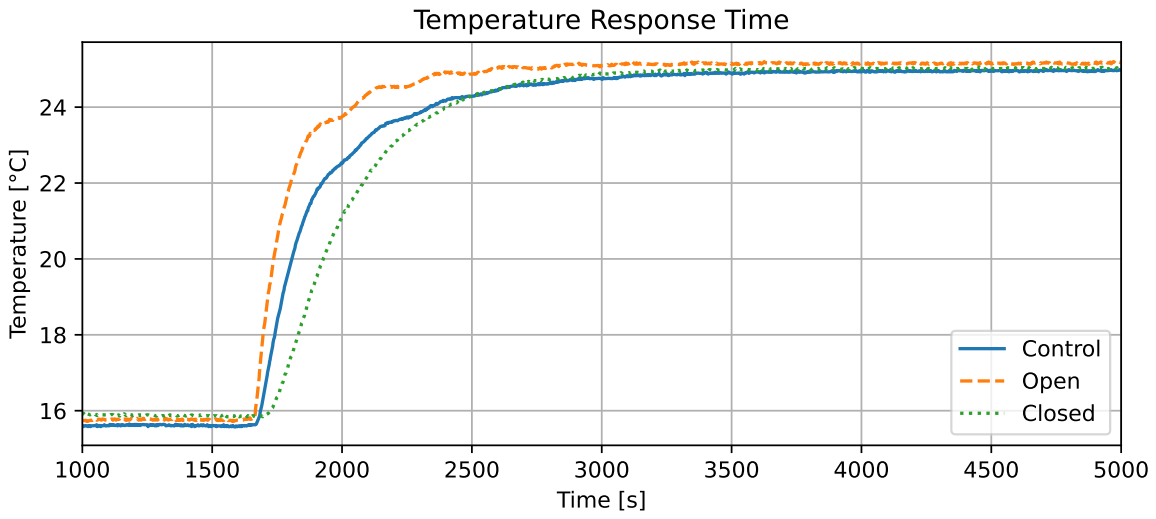
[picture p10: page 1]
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

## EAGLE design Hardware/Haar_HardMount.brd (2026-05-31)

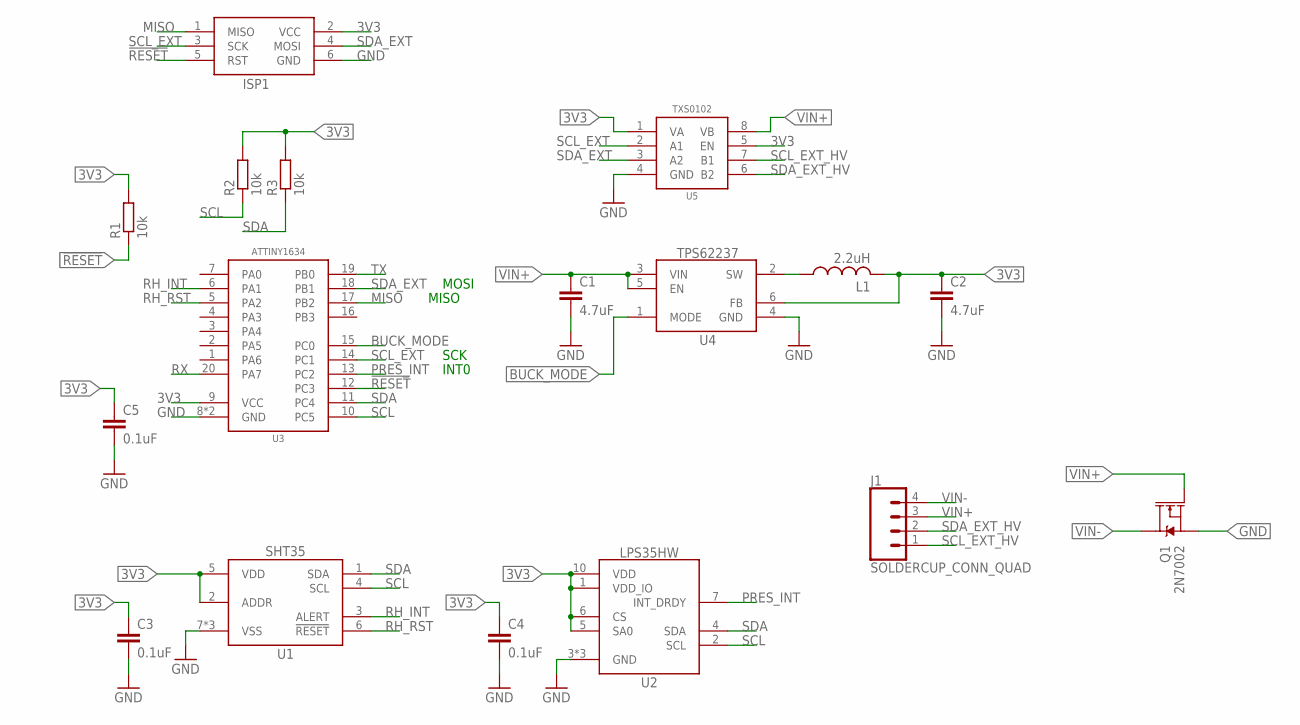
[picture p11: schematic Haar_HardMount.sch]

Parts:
C1, C2: 4.7uF; C0402; MPN GRM155R61A475MEAAD; DIGIKEY 490-14306-1-ND
C3, C4, C5: 0.1uF; C0402
ISP1: AVRISP1.27MM; 2X3_1.27
J1: SOLDERCUP_CONN_QUAD
L1: 2.2uH; 0805; MPN 74479775222; DIGIKEY 732-2953-1-ND
Q1: 2N7002; SOT323
R1, R2, R3: 10k; R0402
U1: SHT35DFN; DFN_8_2.5X2.5
U2: LPS35HW; CCLGA10L
U3: ATTINY1634QFN; QFN20
U4: TPS62237DRY; DRY0006A
U5: TXS0102DQM; DQM_R-PX2SON-N8

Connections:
3V3: C2.1, C3.1, C4.1, C5.1, ISP1.2 (VCC), L1.2, R1.2, R2.2, R3.2, U1.2 (ADDR), U1.5 (VDD), U2.1 (VDD_IO), U2.5 (SA0), U2.6 (CS), U2.10 (VDD), U3.9 (VCC), U4.6 (FB), U5.1 (VA), U5.5 (EN)
!RESET: ISP1.5 (RST), R1.1, U3.12 (PC3)
BUCK_MODE: U3.15 (PC0), U4.1 (MODE)
GND: C1.2, C2.2, C3.2, C4.2, C5.2, ISP1.6 (GND), Q1.2 (S), U1.7 (VSS), U1.8 (VSS), U1.EP (VSS), U2.3 (GND), U2.8 (GND), U2.9 (GND), U3.8 (GND), U3.EP (GND), U4.4 (GND), U5.4 (GND)
MISO: ISP1.1 (MISO), U3.17 (PB2)
unnamed: L1.1, U4.2 (SW)
PRES_INT: U2.7 (INT_DRDY), U3.13 (PC2)
RH_INT: U1.3 (ALERT), U3.6 (PA1)
RH_RST: U1.6 (!RESET), U3.5 (PA2)
RX: U3.20 (PA7)
SCL: R2.1, U1.4 (SCL), U2.2 (SCL), U3.10 (PC5)
SCL_EXT: ISP1.3 (SCK), U3.14 (PC1), U5.2 (A1)
SCL_EXT_HV: J1.1, U5.7 (B1)
SDA: R3.1, U1.1 (SDA), U2.4 (SDA), U3.11 (PC4)
SDA_EXT: ISP1.4 (MOSI), U3.18 (PB1), U5.3 (A2)
SDA_EXT_HV: J1.2, U5.6 (B2)
TX: U3.19 (PB0)
VIN+: C1.1, J1.3, Q1.1 (G), U4.3 (VIN), U4.5 (EN), U5.8 (VB)
VIN-: J1.4, Q1.3 (D)

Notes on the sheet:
MOSI
MISO
SCK
INT0

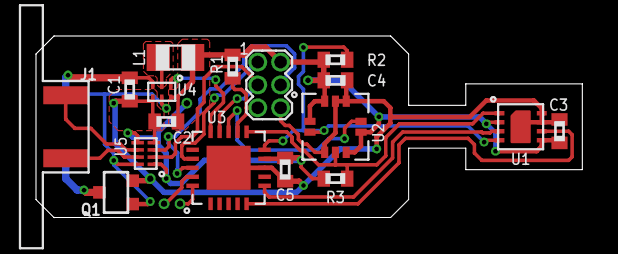
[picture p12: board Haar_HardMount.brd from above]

Board: 2 copper layers, 30.4 x 10.1 mm, 17 parts (0 on the bottom side), 17 nets.

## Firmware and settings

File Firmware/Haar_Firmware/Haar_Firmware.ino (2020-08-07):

//Haar_Firmware_Test.ino

#include "SlowSoftI2CMaster.h"
#include <avr/sleep.h>
#include <avr/power.h>
#include "WireS.h"


#define SHT31_ADDR    0x45
#define LPS35HW_ADDR 	0x5D ///< LPS35HW default i2c address

#define SHT31_MEAS_HIGHREP_STRETCH 0x2C06
#define SHT31_MEAS_MEDREP_STRETCH  0x2C0D
#define SHT31_MEAS_LOWREP_STRETCH  0x2C10
#define SHT31_MEAS_HIGHREP         0x2400
#define SHT31_MEAS_MEDREP          0x240B
#define SHT31_MEAS_LOWREP          0x2416
#define SHT31_READSTATUS           0xF32D
#define SHT31_CLEARSTATUS          0x3041
#define SHT31_SOFTRESET            0x30A2
#define SHT31_HEATEREN             0x306D
#define SHT31_HEATERDIS            0x3066

#define LPS35HW_CTRL_REG1     0x10 ///< Control register 1
#define LPS35HW_CTRL_REG2     0x11 ///< Control register 2
#define LPS35HW_CTRL_REG3     0x12 ///< Control register 3
#define LPS35HW_PRESS_OUT_XL  0x28 ///< Pressure low byte
#define LPS35HW_PRESS_OUT_L   0x29 ///< Pressure mid byte
#define LPS35HW_PRESS_OUT_H   0x2A ///< Pressure high byte
#define LPS35HW_TEMP_OUT_L    0x2B ///< Temperature low byte
#define LPS35HW_TEMP_OUT_H    0x2C ///< Temperature high byte

#define LPS35HW_CTRL_REG2_DEFAULT 0x10

#define READ 0x01
#define WRITE 0x00

unsigned long ReadTimeout = 100; //Wait at most 100ms for new read

uint8_t Config = 0; //Global config value

uint8_t Reg[10] = {0}; //Initialize registers
bool Sample = true; //Flag used to start a new converstion
bool Sleep = false; //Used to put the device into deep sleep //ADD
bool Startup = false;

uint16_t ST, SRH; //Global values for RH sensor (FIX!!!!)

volatile uint8_t ADR = 0x42; //Use arbitraty address, change using generall call??

SlowSoftI2CMaster si = SlowSoftI2CMaster(PIN_C4, PIN_C5, true);  //Initialize software I2C

volatile bool StopFlag = false; //Used to indicate a stop condition
volatile uint8_t RegID = 0; //Used to denote which register will be read from
volatile bool RepeatedStart = false; //Used to show if the start was repeated or not

void setup() {
	pinMode(15, OUTPUT); //DEBUG!
	digitalWrite(15, HIGH); //DEBUG!
	Reg[0] = 0x00; //Set Config to POR value
	Wire.begin(ADR);  //Begin slave I2C

	Wire.onAddrReceive(addressEvent); // register event
	Wire.onRequest(requestEvent);     // register event
	Wire.onReceive(receiveEvent);
	Wire.onStop(stopEvent);

  	si.i2c_init(); //Begin I2C master
  	// Serial.begin(4800); //DEBUG!
  	RHreset(); //Reset RH sensor on startup
  	PresReset(); //Reset pressure sensor on startup

  	WriteByte(LPS35HW_ADDR, LPS35HW_CTRL_REG3, 0x40);; //Setup 50Hz data rate //DEBUG!

}

void loop() {
	Sample = BitRead(Reg[0], 0);

	if(Sample == true || Startup == false) {  //FIX!!! Make first conversion cleaner
		WriteByte(LPS35HW_ADDR, LPS35HW_CTRL_REG2, LPS35HW_CTRL_REG2_DEFAULT | 0x01); //Set ONE_SHOT bit in order to trigger new conversion for pressure
		readRH(); //Get new temp/RH values
		SplitAndLoad(0x04, ST); //Load temp from RH sensor
		SplitAndLoad(0x09, SRH); //Load RH
		ReadPres(); //FIX!!! Make non-blocking/parellel conversion

		Reg[0] = Reg[0] & 0xFE; //Clear sample bit in register
		Sample = false; //Clear sample bit
		Startup = true; //Set after first conversion
	}

	//Sleep after loading registers
	// ADCSRA &= ~(1<<ADEN); //Disable ADC
	// SPCR   &= ~_BV(SPE); //Disable SPI
	//    PRR = 0xFF;
  	digitalWrite(15, LOW); //DEBUG!

	if(Sleep) set_sleep_mode(SLEEP_MODE_PWR_DOWN);
	else set_sleep_mode(SLEEP_MODE_STANDBY);
	sleep_enable();
	sleep_mode(); //Waits here while in sleep mode

	sleep_disable(); //Wake up
	TWSCRA = bit(TWEN);  //Re-enable I2C
	Wire.begin(ADR);
	si.i2c_init(); //Begin I2C master


	delay(10); //DEBUG!
}

uint16_t readStatusRH(void) {
  writeCommand(SHT31_READSTATUS);
  si.i2c_start((SHT31_ADDR << 1) | READ);
  // Wire.requestFrom(SHT31_ADDR, (uint8_t)3);
  uint16_t stat = si.i2c_read(false);;
  stat <<= 8;
  stat |= si.i2c_read(false);;
  //Serial.println(stat, HEX);
  return stat;
}

void RHreset(void) {
  writeCommand(SHT31_SOFTRESET);
  delay(10);
}

void PresReset(void) {
	Serial.println(WriteByte(LPS35HW_ADDR, LPS35HW_CTRL_REG2, 0x04)); //Set bit 2 in CtrlReg2 to force a software reset //DEBUG!
}

void heater(boolean h) {
  if (h)
    writeCommand(SHT31_HEATEREN);
  else
    writeCommand(SHT31_HEATERDIS);
}



// int16_t readTemperatureRH(void) {
//   if (! readTempHum()) return NAN;

//   return ST;
// }


// uint16_t readHumidity(void) {
//   if (! readTempHum()) return NAN;

//   return SRH;
// }
bool ReadPres(void) {
	// WriteByte(LPS35HW_ADDR, LPS35HW_CTRL_REG2, LPS35HW_CTRL_REG2_DEFAULT | 0x01); //Set ONE_SHOT bit in order to trigger new conversion
	unsigned long Timeout = millis();
	bool Done = false; //Flag to wait for new data
	while((millis() - Timeout) < ReadTimeout && !Done) {
		if(BitRead(ReadByte(LPS35HW_ADDR, LPS35HW_CTRL_REG2), 0) == 0) { //Wait for ONE_SHOT to be cleared
			Done = true; //Set flag
		}
	}
	if(Done) {  //If read succesfully
		Reg[0x06] = ReadByte(LPS35HW_ADDR, LPS35HW_PRESS_OUT_XL); //Read out LSB
		Reg[0x07] = ReadByte(LPS35HW_ADDR, LPS35HW_PRESS_OUT_L); //Read out Mid byte
		Reg[0x08] = ReadByte(LPS35HW_ADDR, LPS35HW_PRESS_OUT_H); //Read out MSB

		Reg[0x02] = ReadByte(LPS35HW_ADDR, LPS35HW_TEMP_OUT_L); //Read out LSB
		// Reg[0x02] = 10;
		Reg[0x03] = ReadByte(LPS35HW_ADDR, LPS35HW_TEMP_OUT_H); //Read out MSB
	}
	return Done; //Return valid status
}

boolean readRH(void) {
  uint8_t readbuffer[6];

  writeCommand(SHT31_MEAS_HIGHREP);

  delay(30);  //FIX! Read byte and test for NACK value
  // Wire.requestFrom(SHT31_ADDR, (uint8_t)6);
  si.i2c_start((SHT31_ADDR << 1) | READ);
  // if (Wire.available() != 6) //FIX??
    // return false;
  for (uint8_t i=0; i<6; i++) {
    readbuffer[i] = si.i2c_read(false);
  //  Serial.print("0x"); Serial.println(readbuffer[i], HEX);
  }
  si.i2c_stop();
  // uint16_t ST, SRH;
  ST = readbuffer[0];
  ST <<= 8;
  ST |= readbuffer[1];

  if (readbuffer[2] != crc8(readbuffer, 2)) return false;

  SRH = readbuffer[3];
  SRH <<= 8;
  SRH |= readbuffer[4];

  if (readbuffer[5] != crc8(readbuffer+3, 2)) return false;

//  // Serial.print("ST = "); Serial.println(ST);
//   double stemp = ST;
//   stemp *= 175;
//   stemp /= 0xffff;
//   stemp = -45 + stemp;
//   temp = stemp;

// //  Serial.print("SRH = "); Serial.println(SRH);
//   double shum = SRH;
//   shum *= 100;
//   shum /= 0xFFFF;

//   humidity = shum;

  return true;
}

void writeCommand(uint16_t cmd) {
  // Wire.beginTransmission(SHT31_ADDR);
  si.i2c_start((SHT31_ADDR << 1) | WRITE);
  si.i2c_write(cmd >> 8);
  si.i2c_write(cmd & 0xFF);
  // Wire.endTransmission();
  si.i2c_stop();
}

uint8_t crc8(const uint8_t *data, int len)
{
/*
*
 * CRC-8 formula from page 14 of SHT spec pdf
 *
 * Test data 0xBE, 0xEF should yield 0x92
 *
 * Initialization data 0xFF
 * Polynomial 0x31 (x8 + x5 +x4 +1)
 * Final XOR 0x00
 */

  const uint8_t POLYNOMIAL(0x31);
  uint8_t crc(0xFF);

  for ( int j = len; j; --j ) {
      crc ^= *data++;

      for ( int i = 8; i; --i ) {
	crc = ( crc & 0x80 )
	  ? (crc << 1) ^ POLYNOMIAL
	  : (crc << 1);
      }
  }
  return crc;
}


/////////// Utility Functions///////////////
bool BitRead(uint8_t Val, uint8_t Pos) //Read the bit value at the specified position
{
	return (Val >> Pos) & 0x01;
}

uint8_t SendCommand(uint8_t Adr, uint8_t Command)
{
    si.i2c_start((Adr << 1) | WRITE);
    bool Error = si.i2c_write(Command);
    // si.i2c_stop(); //DEBUG!
    return 1; //DEBUG!
}

uint8_t WriteWord(uint8_t Adr, uint8_t Command, unsigned int Data)  //Writes value to 16 bit register
{
	si.i2c_start((Adr << 1) | WRITE);
	si.i2c_write(Command); //Write Command value
	si.i2c_write(Data & 0xFF); //Write LSB
	uint8_t Error = si.i2c_write((Data >> 8) & 0xFF); //Write MSB
	si.i2c_stop();
	return Error;  //Invert error so that it will return 0 is works
}

uint8_t WriteByte(uint8_t Adr, uint8_t Command, uint8_t Data)  //Writes value to 16 bit register
{
	si.i2c_start((Adr << 1) | WRITE);
	si.i2c_write(Command); //Write Command value
	uint8_t Error = si.i2c_write((Data) & 0xFF); //Write MSB
	si.i2c_stop();
	return Error;  //Invert error so that it will return 0 is works
}

uint8_t WriteWord_LE(uint8_t Adr, uint8_t Command, unsigned int Data)  //Writes value to 16 bit register
{
	si.i2c_start((Adr << 1) | WRITE);
	si.i2c_write(Command); //Write Command value
	si.i2c_write((Data >> 8) & 0xFF); //Write MSB
	si.i2c_write(Data & 0xFF); //Write LSB
	si.i2c_stop();
	// return Error;  //Invert error so that it will return 0 is works
}

// uint8_t WriteConfig(uint8_t Adr, uint8_t NewConfig)
// {
// 	si.i2c_start((Adr << 1) | WRITE);
// 	si.i2c_write(CONF_CMD);  //Write command code to Config register
// 	uint8_t Error = si.i2c_write(NewConfig);
// 	si.i2c_stop();
// 	if(Error == true) {
// 		Config = NewConfig; //Set global config if write was sucessful
// 		return 0;
// 	}
// 	else return -1; //If write failed, return failure condition
// }

int ReadByte(uint8_t Adr, uint8_t Command, uint8_t Pos) //Send command value, and high/low byte to read, returns desired byte
{
	bool Error = SendCommand(Adr, Command);
	si.i2c_rep_start((Adr << 1) | READ);
	uint8_t ValLow = si.i2c_read(false);
	uint8_t ValHigh = si.i2c_read(false);
	si.i2c_stop();
	Error = true; //DEBUG!
	if(Error == true) {
		if(Pos == 0) return ValLow;
		if(Pos == 1) return ValHigh;
	}
	else return -1; //Return error if read failed

}

int ReadByte(uint8_t Adr, uint8_t Command) //Send command value, and high/low byte to read, returns desired byte
{
	bool Error = SendCommand(Adr, Command);
	si.i2c_rep_start((Adr << 1) | READ);
	// si.i2c_start((Adr << 1) | READ);
	uint8_t Val = si.i2c_read(true);
	si.i2c_stop();
	Error = true; //DEBUG!
	if(Error == true) {
		return Val;
	}
	else return -1; //Return error if read failed

}

int ReadWord(uint8_t Adr, uint8_t Command)  //Send command value, returns entire 16 bit word
{
	bool Error = SendCommand(Adr, Command);
	Serial.print("Error = "); Serial.println(Error); //DEBUG!
	si.i2c_rep_start((Adr << 1) | READ);
	uint8_t ByteLow = si.i2c_read(false);  //Read in high and low bytes (big endian)
	uint8_t ByteHigh = si.i2c_read(false);
	si.i2c_stop();
	// if(Error == true) return ((ByteHigh << 8) | ByteLow); //If read succeeded, return concatonated value
	// else return -1; //Return error if read failed
	return ((ByteHigh << 8) | ByteLow); //DEBUG!
}

int ReadWord_LE(uint8_t Adr, uint8_t Command)  //Send command value, returns entire 16 bit word
{
	bool Error = SendCommand(Adr, Command);
	si.i2c_stop();
	si.i2c_start((Adr << 1) | READ);
	uint8_t ByteHigh = si.i2c_read(false);  //Read in high and low bytes (big endian)
	uint8_t ByteLow = si.i2c_read(false);
	si.i2c_stop();
	// if(Error == true) return ((ByteHigh << 8) | ByteLow); //If read succeeded, return concatonated value
	// else return -1; //Return error if read failed
	return ((ByteHigh << 8) | ByteLow); //DEBUG!
}

void SplitAndLoad(uint8_t Pos, unsigned int Val) //Write 16 bits
{
	uint8_t Len = sizeof(Val);
	for(int i = Pos; i < Pos + Len; i++) {
		Reg[i] = (Val >> (i - Pos)*8) & 0xFF; //Pullout the next byte
	}
}

void SplitAndLoad(uint8_t Pos, long Val)  //Write 32 bits
{
	uint8_t Len = sizeof(Val);
	for(int i = Pos; i < Pos + Len; i++) {
		Reg[i] = (Val >> (i - Pos)*8) & 0xFF; //Pullout the next byte
	}
}

boolean addressEvent(uint16_t address, uint8_t count)
{
	RepeatedStart = (count > 0 ? true : false);
	return true; // send ACK to master
}

void requestEvent()
{
	//Allow for repeated start condition
	if(RepeatedStart) {
		for(int i = 0; i < 2; i++) {
			Wire.write(Reg[RegID + i]);
		}
	}
	else {
		Wire.write(Reg[RegID]);
	}
}

void receiveEvent(int DataLen)
{
    //Write data to appropriate location
    if(DataLen == 2){
	    //Remove while loop??
	    while(Wire.available() < 2); //Only option for writing would be register address, and single 8 bit value
	    uint8_t Pos = Wire.read();
	    uint8_t Val = Wire.read();
	    //Check for validity of write??
	    Reg[Pos] = Val; //Set register value
	}

	if(DataLen == 1){
		RegID = Wire.read(); //Read in the register ID to be used for subsequent read
	}
}

void stopEvent()
{
	StopFlag = true;
	//End comunication
}

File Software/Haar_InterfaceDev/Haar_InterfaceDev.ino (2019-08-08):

#include "Margay.h"
#include <Wire.h>

enum Sensor {
	RH = 0,
	Pressue = 1
};

#define CTRL1 0x00
#define TEMP_PRES 0x02
#define TEMP_RH 0x04
#define PRES_REG 0x06
#define RH_REG 0x09

uint8_t ADR = 0x40; //Global address

Margay Logger(Model_1v0, Build_B);

void setup() 
{
	Logger.PowerAux(OFF); 
	delay(500); //Cycle power 
	Logger.PowerAux(ON);  //Turn on external power

	Wire.begin();
	Serial.begin(9600); //Initalze serial for output

  Wire.beginTransmission(0x40);
  Wire.write(0x00);
  Wire.write(0x01);
  Serial.println(Wire.endTransmission());
}

void loop() 
{
  Wire.beginTransmission(0x40);
  Wire.write(0x00);
  Wire.write(0x01);
  Serial.println(Wire.endTransmission());
  delay(50);
	//Print data
	Serial.println("Begin Data...");
	Serial.print("Temp, RH = "); Serial.print(GetTemp(RH)); Serial.println("°C");
	Serial.print("Temp, Pres = "); Serial.print(GetTemp(Pressue)); Serial.println("°C");
	Serial.print("Pressure = "); Serial.print(GetPressure()); Serial.println("mBar");
	Serial.print("Humidity = "); Serial.print(GetRH()); Serial.println("%");
	Serial.println("... End Data");
	delay(1000); //Wait a bit
}

float GetPressure()   //Returns pressure [mBar]
{
	uint32_t Val = 0; //Val for getting/calculating pressure value
	// uint8_t Data[3] = {0}; //Storage for byte values
//	Wire.beginTransmission(ADR);
//	Wire.write(PRES_REG);
//	Wire.endTransmission();
//	Wire.requestFrom(ADR, 3);
//	while(Wire.available() < 3); //Wait for data to be ready //FIX!!!
  uint32_t Temp = 0; //DEBUG
	for(int i = 0; i < 3; i++) {
		// Data[i] = Wire.read(); //Read in 24 bit value
//		Val = (Val << 8) | Wire.read();
    Wire.beginTransmission(ADR);
    Wire.write(PRES_REG + i);
    Wire.endTransmission();
    Wire.requestFrom(ADR, 1);
    Temp = Wire.read(); //DEBUG!
    Val = (Temp << 8*i) | Val; //DEBUG!
//    Serial.println(Val, HEX); //DEBUG!
	}
	// Val = (Data[2] << 16) | (Data[1] << 8) | Data[0]; //Concatonate values 

//	if (Val & 0x800000){  //Sign extend if required 
//      Val = (0xFF000000 | Val);
//    }

  	return (Val / 4096.0);
}

float GetRH()  //Returns humidity [%]
{
	float Val = 0; //Val for getting/calculating RH value
	Val = GetWord(RH_REG);
	Val = (100.0*Val)/65535.0;  //Convert to RH
	return Val;
}

float GetTemp(Sensor Device)  //Returns temp [C], pass which sensor is desired 
{
	float Val = 0; //Val for getting/calculating temp value
	if(Device == Pressue) {
		Val = GetWord(TEMP_PRES);
		Val = Val/100.0; //Convert to C
	}

	else if (Device == RH) {
		Val = GetWord(TEMP_RH);
		Val = ((Val*175.0)/65535.0) - 45; //Convert to C
	}
	return Val;
}

uint16_t GetWord(uint8_t Reg)  //Returns word, read from Reg position
{
	uint16_t Val = 0; //Val to be read from device
	Wire.beginTransmission(ADR);
	Wire.write(Reg);
	Wire.endTransmission();

	Wire.requestFrom(ADR, 1);  //Request word
//	while(Wire.available() < 2); //Wait //FIX! Add timeout
	Val = Wire.read();
//  Serial.println(Val, HEX);

  Wire.beginTransmission(ADR);
  Wire.write(Reg + 1);
  Wire.endTransmission();
  Wire.requestFrom(ADR, 1);  //Request word
	Val = Val | (Wire.read() << 8);  //Concatonate 16 bits 
//  Val = Wire.read() | (Val << 8);  //Concatonate 16 bits //DEBUG!
	return Val; 
}

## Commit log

2019-03-27 Initial layout and schematic
    First cut schematic and layout, needs additional logic lines added on schematic and general layout improvement
    [Haar.brd, Haar.sch]
2019-03-27 Added HardMount version, improved layout on conventional version
    [Haar_HardMount.brd, Haar_HardMount.sch]
2019-04-19 Fixed ISP error, updated notes
    Fixed an errant connection to the ISP header on both versions in schematic, still need to fix the layout. Also removed outdated notes on schematic
    [Haar.brd, Haar.sch, Haar_HardMount.brd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]
2019-04-21 Reroute; dimensions
    [Haar_HardMount.brd]
2019-04-22 Fixed routing, cleaned up, ready for fab
    Minor routing fixes, added some silkscreen, generated gerbers, ready for prototype fab
    [Haar_HardMount.brd]
2019-04-25 Generated Gerbers, ready to fab
2019-04-26 Minor dimensional cleanup, final gerbers generated
    Fixed dimensional alignment, generated gerbers, sent to fab
    [Haar_HardMount.brd, Haar_HardMount.sch]
2019-06-13 Updated part values, added prelim firmware
    Added values to parts for full BoM generation, added preliminary test firmware, consolidation and streamlining to come, simply proof of functionality at the moment
    [Haar_HardMount.brd, Haar_HardMount.sch, Haar_HardMount_BOM.csv]
2019-06-27 Beveled corners on board
    [Haar_HardMount.brd]
2019-07-02 Minor cleanup on board, fixed #1, sent v0.1 to fab
    Minor board cleanup, added pullup resistors on internal I2C lines, fixed #1 issue
    [Haar_HardMount.brd, Haar_HardMount.sch]
2019-08-08 Minor improvements to increase speed of startup and reliability
    Increased startup speed by removing some delays, added additional deep sleep mode, need to add support for this via I2C, used lighter sleep mode for normal operation, continual testing required to re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
2020-02-20 Generated fab quote
    Updated part values for inductor and capacitor in Eagle, generated new BoM and zipped into file for quote generation
    [Haar_HardMount.brd, Haar_HardMount.sch, Haar_HardMount_BOM.csv]
2020-04-26 rm old Gerbers; see prior releases
2020-04-30 Schematic images for upcoming README updates
2020-04-30 Housing main cylinder
    [Haar_Body.SLDPRT, Haar_Body.STL]
2020-05-07 Annotated board photo
2020-05-24 connections: not included in BoM CSV (board only)
2020-05-24 0.05" pitch ICSP header
2020-05-25 Housing, ICSP power
2020-06-02 Upload Using Programmer image: point to Symbiont-LiDAR
2020-06-02 Housing and now-detailed cabling into Assembly section
2020-08-06 Symbiont --> Haar; VCC/GND cable colors flipped (FIXED!)
2020-08-08 HardMount plug: solder attachment, wiring
2020-08-08 "Bootloader" for setting fuses
2020-08-10 Input range 3.3V to 5.5V
2020-09-08 Cable length / I2C warning (3 m)
2020-09-08 Cables: multiple materials and lengths
2020-09-08 Link to only those cables with all 4 positions loaded
2020-09-28 Added dimensional drawings
    [Haar_HardMount.brd]
2021-07-19 ISP driver note
2023-10-26 Added first iteration of testing documentation
    [StepChangeData.csv]
2023-10-26 Added data analysis code
    Added analysis code and outputs for pressure, temp and RH testing
    [Data.csv]
2023-10-26 Fixed pressure doc linkage
2023-10-26 Removed leading row of CSV for format
    [Data.csv]
2024-08-21 Extensive documentation updates
    - Updates to data used in temp and RH testing
    - Updates to the testing apparatus for temp testing.
    - Added PID controller code
    - Added code for control sensor
    - Many documentation updates in main readme
    - Added methods on construction of mini ICSP cable
    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
    [Data.csv]
2024-08-22 Fixed naming of images in temperature README
2024-08-22 Added step response graphs, mechanical pinout graphic
    - Added step response graphs
    - Added all mechanical parts
    - Added renders of mechanical parts
    - Added Pinout graphic
    [ClosedBody.SLDPRT, ClosedBody.STL, ClosedBody_FDM.SLDPRT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]
2024-08-27 Adjusted folders, added production documents
    Added BoM, added frame to Eagle schematic, moved production files into own folder, renamed folder to `Software`, and moved old design to `legacy` folder.
    [Haar.brd, Haar.sch, Haar_HardMount.brd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]
2026-05-31 Add register map section: current and proposed Schema 1 layouts
    Documents the existing 10-byte prototype register map (no schema byte,
    raw sensor counts, out-of-bounds RH register) alongside the proposed
    NW-Device-Specification Schema 1 layout (Page 0 identity/EEPROM,
    Page 1 sensor data/SRAM grouped by chip, no Page 2 needed).
2026-06-01 README: add NW-Device-Specification Schema 1 Page 0 block
    Documents the device's 32-byte EEPROM identity block per
    https://github.com/NorthernWidget/NW-Device-Specification
2026-06-01 Page 1 status byte: add pan-fault (bit 7), label 0x27 as extended fault byte
    Reflects the NW-Device-Specification Schema 1 standard: bit 7 is the
    pan-fault summary (set when any bit 1–6 is set); 0x27 is reserved as
    the extended fault byte and must be written as 0x00.
2026-06-01 Move extended fault byte to 0x21; sensor data starts at 0x22

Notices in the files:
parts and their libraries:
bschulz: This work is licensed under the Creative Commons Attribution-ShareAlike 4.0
